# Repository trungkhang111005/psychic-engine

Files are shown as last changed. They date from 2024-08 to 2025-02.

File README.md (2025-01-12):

# Psychic-Engine: 3D-Printed RC Car Project

## Table of Contents

1. [Introduction](#1-introduction)
2. [Goals](#2-goals)
3. [Features](#3-features)
4. [Technologies Used](#4-technologies-used)
5. [Project Structure](#5-project-structure)
6. [Getting Started](#6-getting-started)
   - [Prerequisites](#61-prerequisites)
   - [Steps](#62-steps)
   - [Demo Videos](#63-demo-videos)
7. [Challenges and Solutions](#7-challenges-and-solutions)
   - [Electronics](#71-electronics)
   - [Rear Differential Drive](#72-rear-differential-drive)
   - [Steering System](#73-steering-system)
8. [Future Improvements](#8-future-improvements)
9. [License](#9-license)
10. [Acknowledgments](#10-acknowledgments)
11. [Contact](#11-contact)

<div style="text-align: center;">
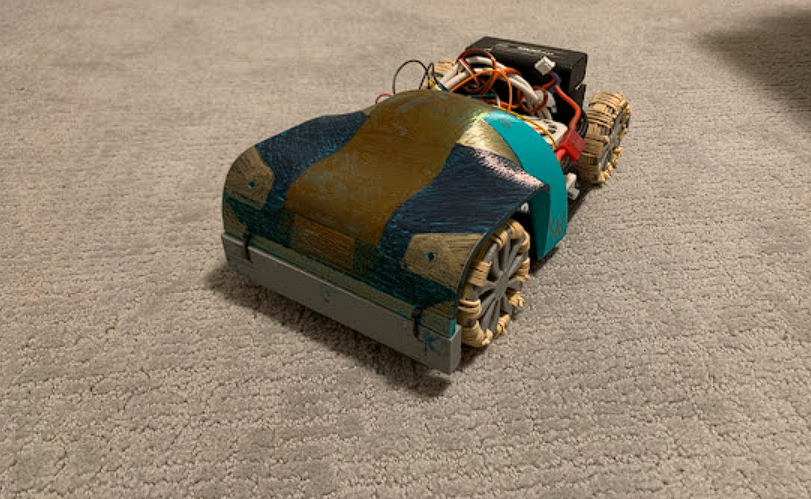
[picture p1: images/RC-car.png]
psychic-engine
    
</div>

## 1. Introduction
This project involves the design, 3D printing, and assembly of a fully functional RC car, controlled by an ESP32 microcontroller. The car features a custom-designed rear differential and a rack-and-pinion steering system based on the Ackerman principle to avoid skidding. All parts are custom-designed, with the exception of a few metal machined parts where higher durability and precision were required.

## 2. Goals

The primary goals of the Psychic-Engine 3D-Printed RC Car Project are to:

1. **Develop a Fully Functional 3D-Printed RC Car**: Design, 3D print, and assemble a reliable and robust RC car using custom-designed parts, ensuring all components fit seamlessly together and perform as intended.

2. **Implement Efficient Control Using ESP32**: Utilize the ESP32 microcontroller to achieve efficient and responsive wireless control of the car.

3. **Incorporate Advanced Steering Mechanisms**: Implement a rack-and-pinion steering system based on the Ackerman principle to improve cornering performance.

4. **Ensure Effective Power Distribution**: Create a custom rear differential that provides balanced power distribution to the wheels.

5. **Facilitate Easy Assembly**: Use snap-fit joints and compliant mechanisms to simplify assembly, reducing the need for machined fasteners.

6. **Prepare for Autonomous Features**: Lay the groundwork for autonomous navigation capabilities by planning for the integration of sensors and control systems.

These goals are designed to guide the project towards developing a versatile and innovative RC car that serves both as a functional prototype and an educational tool.

## 3. Features
1. **Custom 3D-Printed Parts**: Most components are designed in SolidWorks, 3D-printed using PLA and PETG materials.
2. **ESP32 Control**: The car is controlled using an ESP32 microcontroller, providing efficient wireless communication and processing power.
3. **Ackerman Steering System**: The rack-and-pinion steering follows the Ackerman principle to reduce tire wear and improve cornering performance.
4. **Rear Differential**: A custom-designed rear differential ensures smooth power distribution to the wheels, enhancing the car's handling.
5. **Snap Fit Joints**: Compliant mechanism is used to create snap fit joints, eliminating the need for machined fasteners.

## 4. Technologies Used
1. **CAD Software**: SolidWorks
2. **3D Printer**: Sovol SV06
3. **Materials**: PLA (Elegoo) for structural components, PETG (Overture) for functional parts
4. **Microcontroller**: ESP32
5. **Programming Language**: C++ (for Arduino/ESP32 script)

## 5. Project Structure
1. **[Structure](./Structure/)**
   - Contains the **[SolidWorks](./Structure/Solidworks/)** folder with all CAD files.
   - 3D printing instructions
   - Contains the **[Assembly_Instructions](./Structure/Assembly_Instructions/)** folder with detail images of assembly steps
2. **[Electronics](./Electronics/)**
   - Contains the **[Arduino](./Electronics/Arduino/)** folder with ESP32 scripts.
   - Setup instructions for the electronic components.

## 6. Getting Started

### 6.1 Prerequisites
1. SolidWorks (or any CAD software) installed for viewing and modifying CAD files.
2. Slicing software suitable for your printer.
3. Arduino IDE configured to work with ESP32 for uploading the script.
4. A Sovol SV06 3D printer (or any FDM printer) with a print plate size of at least 235x235 mm.

### 6.2 Steps

1. **3D Printing the Parts**:
   - Navigate to the **[Structure](./Structure/)** folder.
   - Follow the instructions provided in the 3D printing instructions file to prepare and print all the necessary components.

2. **Assembling the Car**:
   - Go to the **[Assembly_Instructions](./Structure/Assembly_Instructions/)** subfolder.
   - Follow the detailed assembly instructions provided to assemble the 3D-printed parts into the final RC car structure.

3. **Setting Up Electronics**:
   - Navigate to the **[Electronics](./Electronics/)** folder.
   - Follow the instructions provided to connect the Xbox controller to the ESP32 microcontroller.
   - Refer to the motor/servo wiring instructions to correctly wire the motor and servo to the ESP32.

### 6.3 Demo Videos
RC car in details

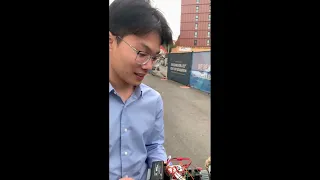
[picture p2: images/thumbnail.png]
Watch me talking about the RC car and a demo of it in action (https://youtu.be/J6uigz7IrvU)


Drifting

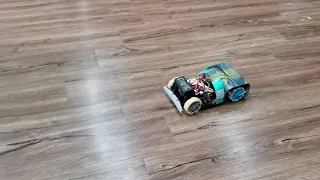
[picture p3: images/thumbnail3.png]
Watch the car drifting (https://youtu.be/YaZgg8Mr1b0?feature=shared)


Testing

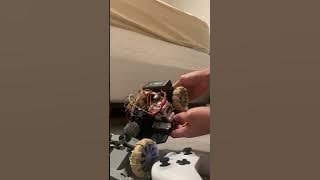
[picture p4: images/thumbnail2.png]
Watch the RC car in testing (https://youtu.be/PcJJqVZroOI?si=CFPb1v_Qr5A0FJ0J)


## 7. Challenges and Solutions

The development of the RC car was segmented into three primary components: electronics, rear differential drive, and steering. Each component presented distinct challenges that required tailored engineering solutions.

### 7.1 Electronics
1. **Challenge**: Difficulty in establishing a Bluetooth Low Energy (BLE) connection between the Xbox controller and the ESP32 microcontroller.
   - **Solution**: After conducting extensive research, the Bluepad library was identified and utilized. This library provided the necessary support for BLE connections, enabling seamless communication between the Xbox controller and the ESP32.

2. **Challenge**: Arming the motor via the Xbox controller and ESP32 was problematic due to the absence of a conventional radio controller.
   - **Solution**: A script found on the [Arduino forum](https://forum.arduino.cc/t/lessons-on-arming-esc-with-arduino/427152) facilitated the identification of the correct arming PWM signals for the ESC. Implementing this script allowed for successful motor arming and control.

### 7.2 Rear Differential Drive
1. **Challenge**: The gearbox experienced displacement from the pinion gear during operation, compromising gear engagement and overall performance.
   - **Solution**: A structural enhancement was made by designing a three-arm system that extends from the chassis to apply pressure on the gearbox, maintaining optimal engagement with the pinion gear. Castor balls were integrated at the arm ends to minimize friction, facilitating smooth high-speed rotation of the ring gear.

2. **Challenge**: High stress concentrations led to frequent axle breakage.
   - **Solution**: Structural integrity was improved by introducing fillets at critical stress points behind the wheel and axle gear, promoting even stress distribution. Additionally, the infill percentage was increased, and a triangular infill pattern was adopted to enhance the axle's durability.

### 7.3 Steering System
1. **Challenge**: Determining the precise length of the steering tie rod was complex, resulting in difficulties in maintaining the steering wheels' alignment.
   - **Solution**: SolidWorks was employed to assemble the steering rack and knuckles in a virtual environment. This facilitated accurate determination of the tie rod length, ensuring consistent and correct alignment of the steering wheels.

2. **Challenge**: The tie rod had a propensity to become misaligned and rotate inwards, risking damage to the servo by causing it to lock or break during excessive rack movement.
   - **Solution**: To mitigate this issue, two structural poles were added to the chassis, acting as physical stops. These stops prevent excessive inward rotation of the tie rods, thereby safeguarding the servo from potential damage.

### Summary

By methodically addressing each engineering challenge, the RC car project achieved a robust and reliable design. The implemented solutions not only resolved the specific issues but also enhanced the car's overall performance and structural integrity, ensuring its capability to withstand various operating conditions.

## 8. Future Improvements

Looking forward, several enhancements are planned to elevate the functionality and user experience of the RC car:

1. **Integrating an IMU and OpenPilot**: To enable autonomous navigation capabilities, the integration of an Inertial Measurement Unit (IMU) along with the [OpenPilot](https://github.com/commaai/openpilot.git) system is proposed. This will allow the car to navigate and maneuver independently based on pre-defined parameters and real-time sensor data.

2. **Adding a First-Person Camera with Microphone**: To enhance the user experience and expand the car's applications, a first-person view (FPV) camera will be installed alongside a microphone to capture ambient sounds. This setup will enable the car to be used for inspections and monitoring in various settings such as factories, construction sites, or natural environments, providing both visual and auditory feedback.

3. **Transitioning to Radio Signal Control**: To extend the operational range and reliability of the control system, the project plans to transition from Bluetooth to radio signal-based control. This shift will allow for longer-range operation and a more stable connection, improving the car’s performance in various environments.

4. **Solar-Powered Charging System**: Integrating solar panels into the car's design is planned to provide an additional power source. This could supplement the battery or allow for continuous operation in sunny conditions, increasing the car's autonomy and reducing the need for frequent battery charging.

## 9. License
- The ESP32 script is licensed under the MIT License.
- The SolidWorks design files are licensed under the Creative Commons Attribution 4.0 International License.

## 10. Acknowledgments
- Special thanks to Brendon Kennard for providing the BLDC motor for this project.
- Thanks to [Bluepad32](https://github.com/ricardoquesada/bluepad32.git) for the initial ESP32 code framework.
- Thanks to [The Engineering Mindset](https://youtu.be/vpbhvxAM0io?si=aknrSyXhpb9AykjJ) for inspiring the modelling of the differntial gearbox model.

## 11. Contact
If you have any questions or want to collaborate, feel free to reach out to me at trungkhang1110@gmail.com.

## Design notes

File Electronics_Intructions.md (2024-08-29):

# Electronics Setup

## Components Needed
- **Controller**: bluetooth supported controller (Xbox, etc.)
- **Microcontroller**: ESP32
- **Motor**: Surpass Hobby Platinum Waterproof Series, 28 mm diameter, 47 mm length
- **ESC**: Surpass Hobby Platinum Waterproof 45 A
- **Buck Converter**: LM2596
- **Servo**: SG 5010
- **MOSFET**: IRL 530N
- **Resistor**: 1 x 100 ohm
- **Jumper Wires**
- **Breadboard**: 1 x mini 20-holes long breadboard
- **Battery**: 2S/3S lithium polymer battery 1500mAh
- **Double-Sided Tape**
- **Rubber Bands**

## Setting Up ESP32 and Bluepad on Arduino IDE
1. **Install the ESP32 Board in Arduino IDE**:
   - Open Arduino IDE.
   - Go to `File > Preferences`.
   - Add these URLs in the "Additional Boards Manager URLs" field:
     ```
     https://espressif.github.io/arduino-esp32/package_esp32_dev_index.json
     https://raw.githubusercontent.com/espressif/arduino-esp32/gh-pages/package_esp32_index.json
     https://raw.githubusercontent.com/ricardoquesada/esp32-arduino-lib-builder/master/bluepad32_files/package_esp32_bluepad32_index.json
     ```
   - Go to `Tools > Board > Boards Manager`, search for "ESP32", and install.
   - Select ESP32 Dev Module board or esp32 board of your choice.

2. **Install Bluepad32 Library**:
   - Go to `Tools > Manage Libraries`, search for "Bluepad32", and install it.

3. **Upload the Arduino Script**:
   - Connect the ESP32 via USB.
   - Open the script from the [](Arduino) folder.
   - Select the correct board and port, then upload the script.
   - turn on your controller and pair the controller with the esp32
## Layout and Wiring
1. **Component Placement**:
   - Place the MOSFET and buck converter on the breadboard.
   - Use double-sided tape and rubber bands for securing components.

2. **Wiring**:
   - **Buck Converter Setup**:
     - Connect the positive of the BEC to the buck converter input.
     - Connect the ground of the BEC to the buck converter ground.
     - Adjust the output to 3.3V.
     - Connect the buck converter output to the 3V3 pin on the ESP32.

   - **Servo Connection**:
     - Place MOSFET on the breadboard without shorting pins.
     - Connect a 100 ohm resistor between the MOSFET gate (1st pin) and ESP32 pin 27.
     - Connect the servo signal wire to ESP32 pin 13.
     - Connect servo power to the same row as BEC positive.

## Testing
1. Power up the setup and verify signals to motor and servo.
2. Use the Arduino IDE serial monitor for debugging.

## Usage
- Power on the car by connecting the battery to the ESP32.
- Use the controller to navigate the car.

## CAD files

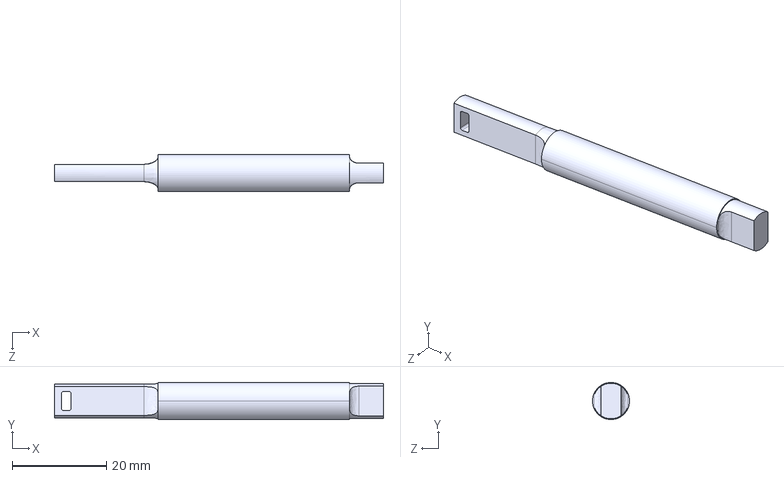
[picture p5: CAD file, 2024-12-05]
Structure/.step/diff axel right side.STEP
70.0 x 7.90 x 7.90 mm

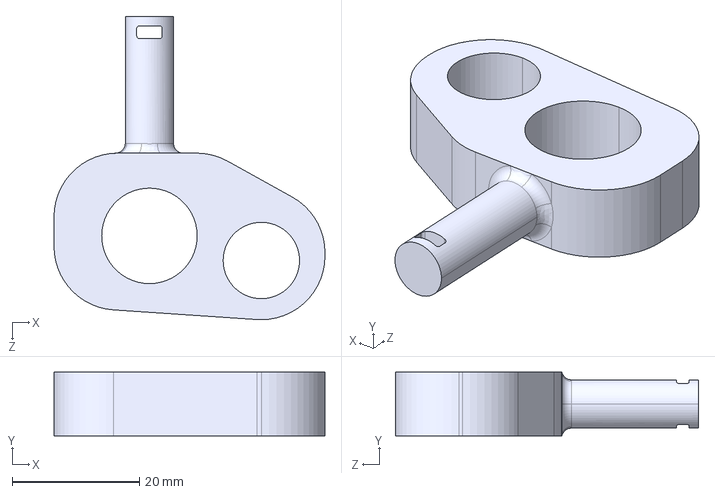
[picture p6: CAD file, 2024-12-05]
Structure/.step/steering knuckle (print 2).STEP
42.6 x 10.0 x 47.7 mm

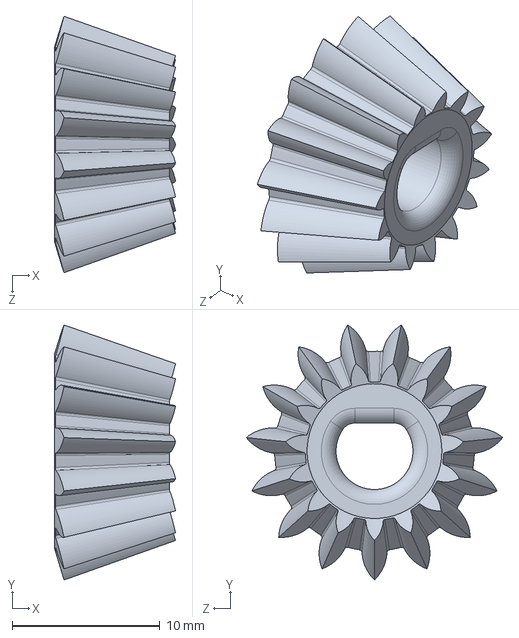
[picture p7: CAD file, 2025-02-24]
Structure/Solidworks/3665 pinion.SLDPRT
8.19 x 17.3 x 17.4 mm

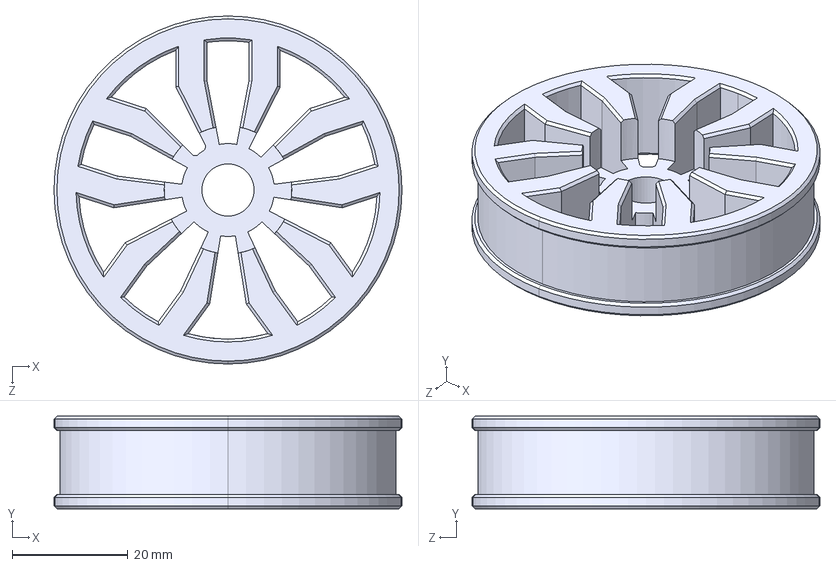
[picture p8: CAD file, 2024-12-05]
Structure/.step/front wheel (print 2).STEP
60.0 x 16.0 x 60.0 mm

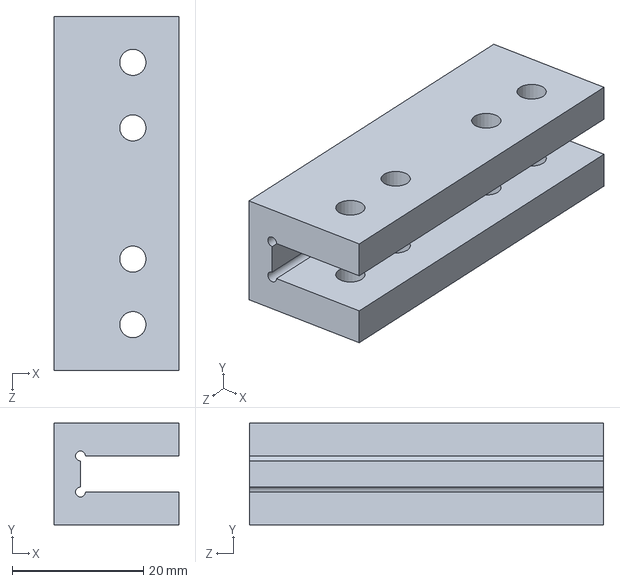
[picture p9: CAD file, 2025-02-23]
Structure/Solidworks/chassis_connector.SLDPRT
19.0 x 15.5 x 54.0 mm

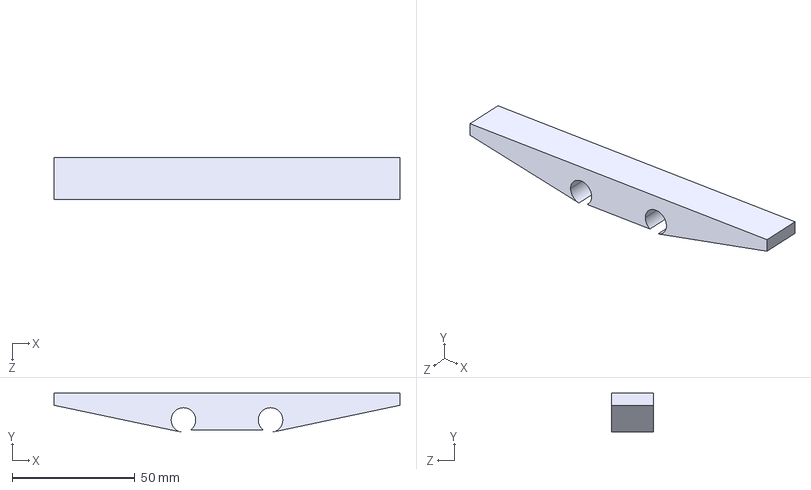
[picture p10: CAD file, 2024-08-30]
Structure/.step/rear bumper.STEP
141.0 x 15.9 x 17.0 mm

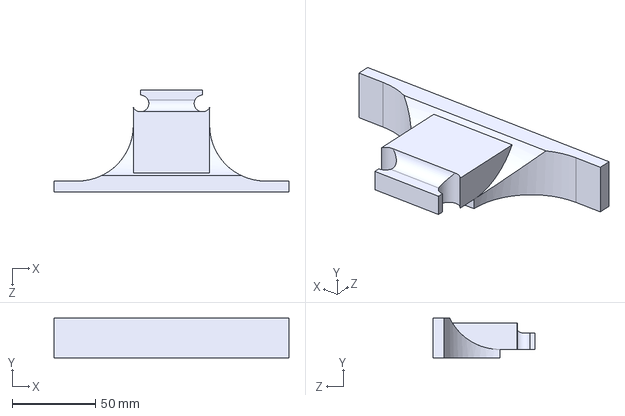
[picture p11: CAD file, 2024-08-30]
Structure/.step/front bumper.STEP
141.0 x 23.7 x 61.1 mm

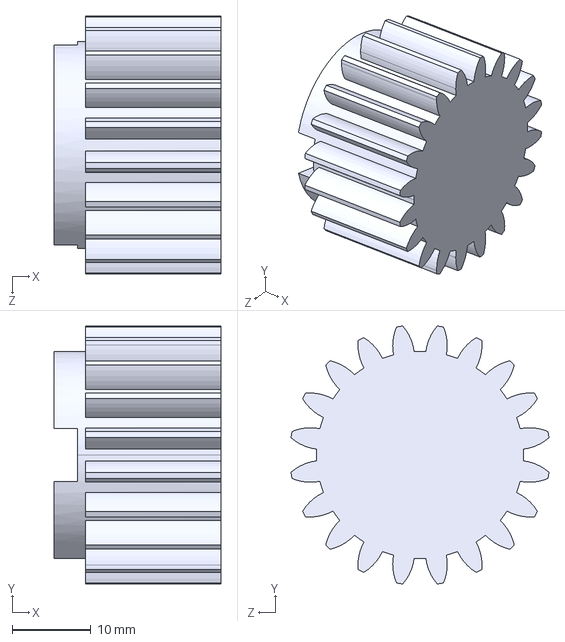
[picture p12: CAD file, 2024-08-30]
Structure/.step/steering pinion.STEP
21.2 x 32.7 x 32.7 mm

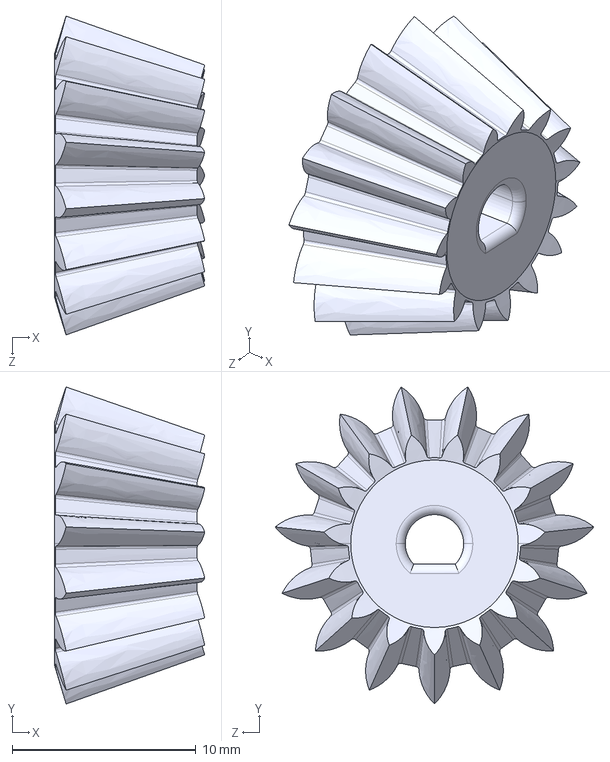
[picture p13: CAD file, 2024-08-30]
Structure/.step/diff pinion gear.STEP
8.19 x 17.3 x 17.4 mm

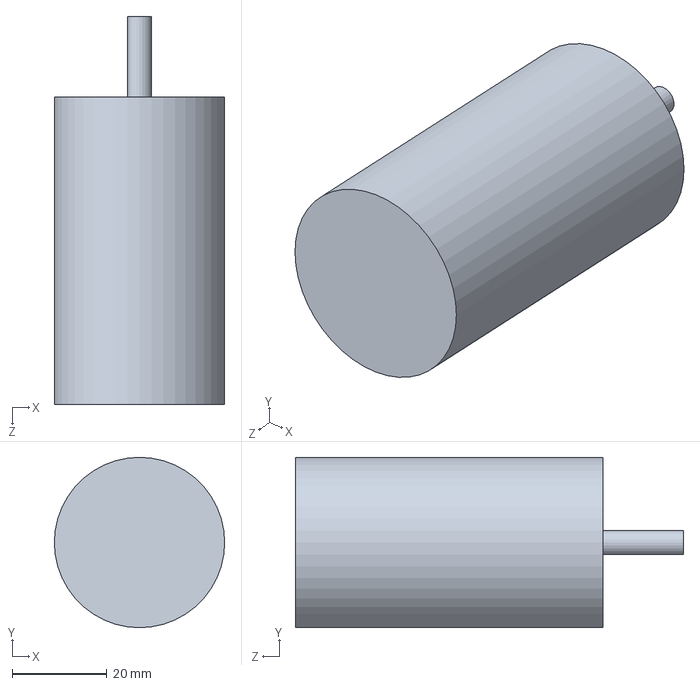
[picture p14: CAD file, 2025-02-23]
Structure/Solidworks/model 3665 motor.SLDPRT
36.0 x 36.0 x 82.0 mm

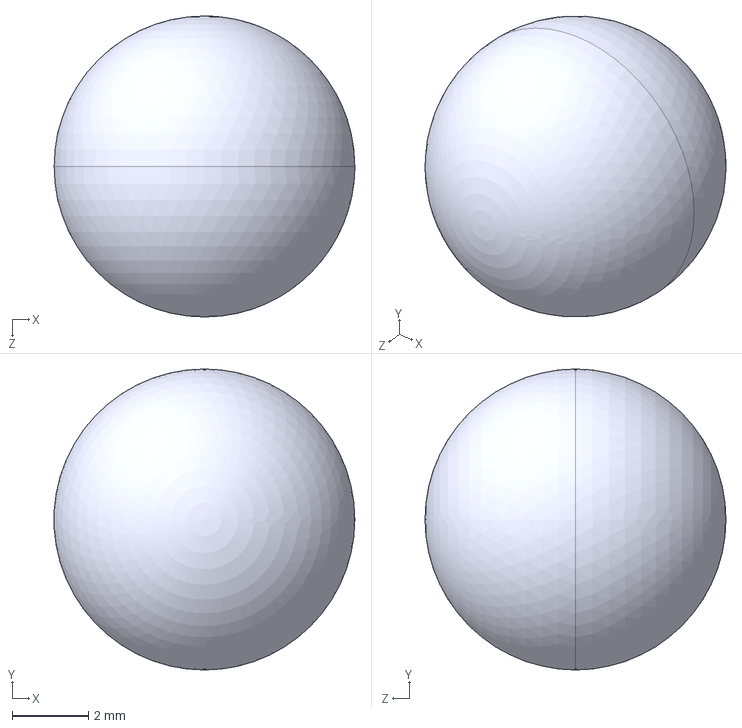
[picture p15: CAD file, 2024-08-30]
Structure/.step/diff ball castor (print 3).STEP
7.89 x 7.90 x 7.90 mm

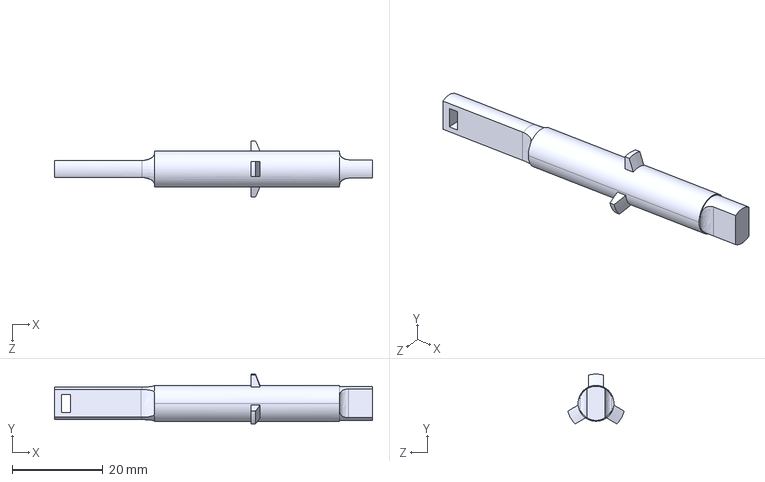
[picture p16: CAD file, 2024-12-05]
Structure/Solidworks/diff axel left side.STEP
70.0 x 11.0 x 12.4 mm

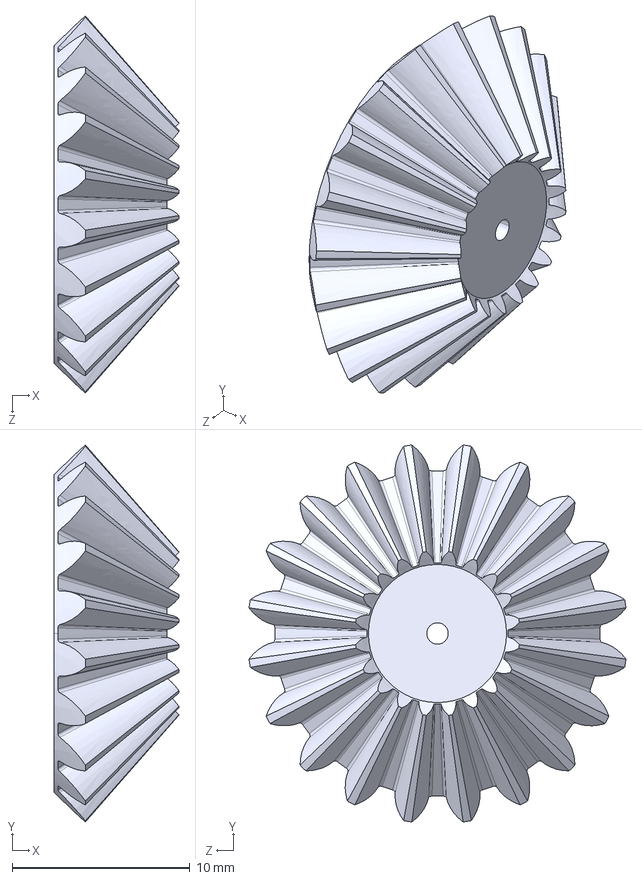
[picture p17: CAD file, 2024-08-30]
Structure/.step/diff case gear (print 2).STEP
7.02 x 21.2 x 21.2 mm

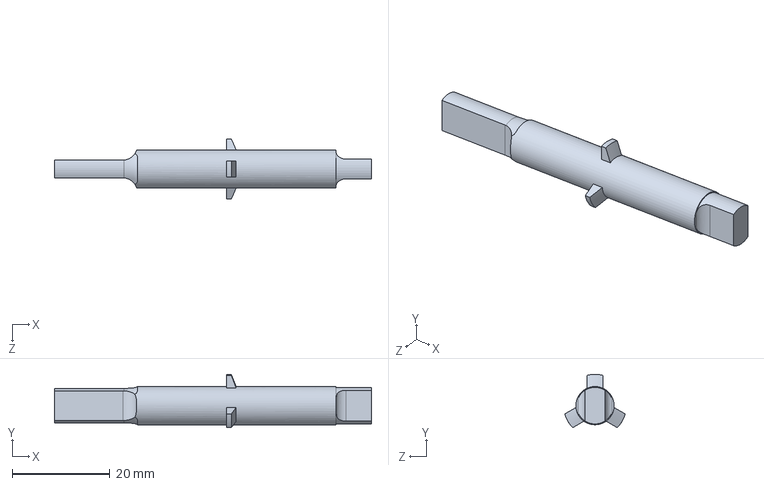
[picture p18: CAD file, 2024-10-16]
Structure/Solidworks/diff axel left side smaller for petg.SLDPRT
65.0 x 10.9 x 12.4 mm

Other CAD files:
Structure/Solidworks/new_assembly.SLDASM
Structure/Solidworks/RC car.SLDASM
Structure/.step/rear wheel (print 2).STEP
Structure/.step/diff ring gear.STEP
Structure/.step/chassis.STEP
Structure/.step/diff axel gear (print 2).STEP
Structure/.step/diff axel left side.STEP
Structure/.step/steering knuckle cover (print 2).STEP
Structure/.step/steering rack.STEP
Structure/.step/steering tie rod (print 2).STEP
Structure/.stl/3665 pinion.STL
Structure/.stl/chassis - Copy (2).STL
Structure/.stl/chassis - Copy.STL
Structure/.stl/chassis.STL
Structure/.stl/chassis_connector.STL
Structure/.stl/diff axel gear (print 2).STL
Structure/.stl/diff axel left side smaller for petg.STL
Structure/.stl/diff axel left side.SLDPRT
Structure/.stl/diff axel left side.STL
Structure/.stl/diff axel right side.STL
Structure/.stl/diff ball castor (print 3).STL
Structure/.stl/diff case gear (print 2).STL
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

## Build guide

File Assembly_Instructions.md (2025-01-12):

# Structure Assembly Guide

## Chassis and Mechanical Assembly

### Step 1: Insert the Castor Balls and Bearings
Insert the 3 castor balls into the rear wheel castor ball slots, then insert the 2 bearings into their respective slots.

<div style="text-align: center;">
    Castor Ball Insertion
</div>

### Step 2: Secure the Motor
Lock the motor into its place with M3 screws. Ensure the screws are firmly tightened, as vibrations from the motor can loosen the screws over time.

<div style="text-align: center;">
    Motor Secured with Screws
</div>

### Step 3: Install the Pinion Gear
Use a bar or F-clamp to press the pinion gear onto the motor shaft. The interference fit requires significant force to install. Make sure the top of the pinion gear aligns with the middle of the side castor ball.

<div style="text-align: center;">
    Pinion Gear Installation
    Pinion Gear Alignment
</div>

### Step 4: Insert the Right Rear Wheel Axle
Insert the right rear wheel axle into its designated slot.

<div style="text-align: center;">
    Right Rear Wheel Axle Insertion
</div>

### Step 5: Assemble the Differential Gearbox
1. Assemble the differential gearbox.
2. Fasten the 2 case gears into the gearbox using the fishing line that runs through both of them. Tie a double knot on top of the gearbox.

   <div style="text-align: center;">
       Differential Gearbox Assembly
   </div>

3. Insert the 2 axle gears simultaneously, placing each on opposite sides of the gearbox first, then pushing them into place. Look down from the top of the gearbox to see if the axle gears are properly aligned (you should be able to see through the axle slots).

   <div style="text-align: center;">
       Axle Gear Insertion
       Axle Gear Alignment Check
   </div>

### Step 6: Position the Gearbox
Slide the gearbox at an angle between the right axle and the pinion gear to fix it in place.

<div style="text-align: center;">
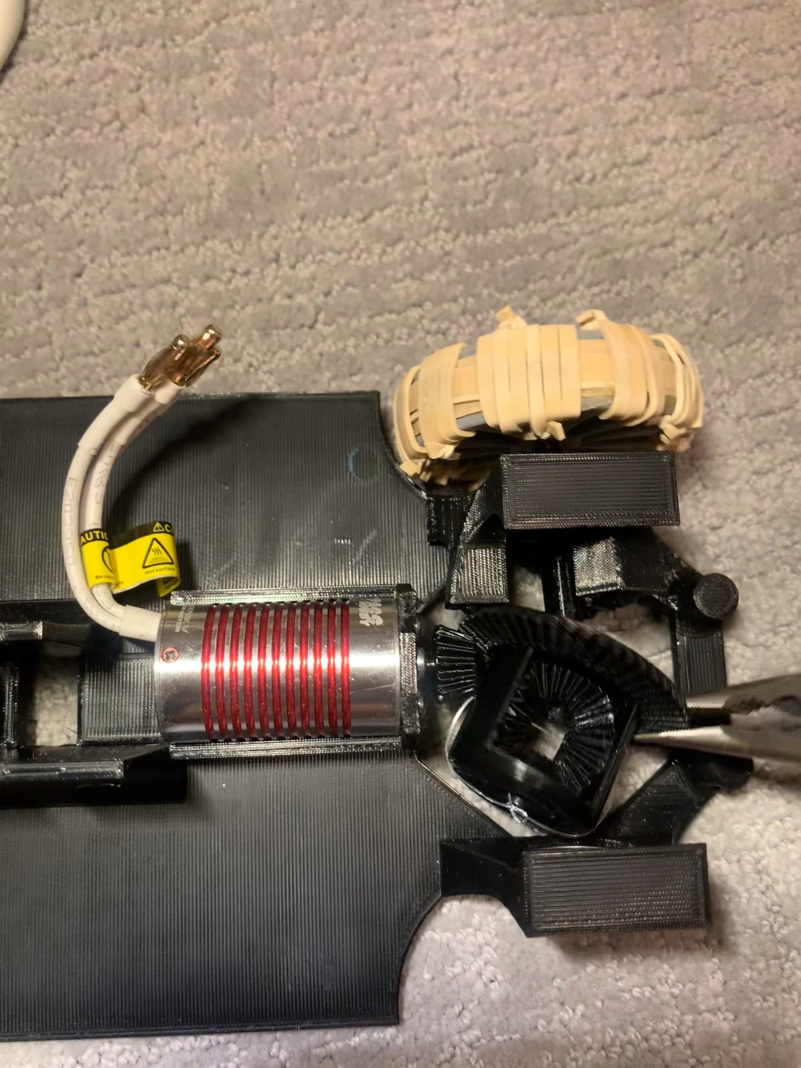
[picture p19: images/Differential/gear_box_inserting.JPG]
Gearbox Positioning
    
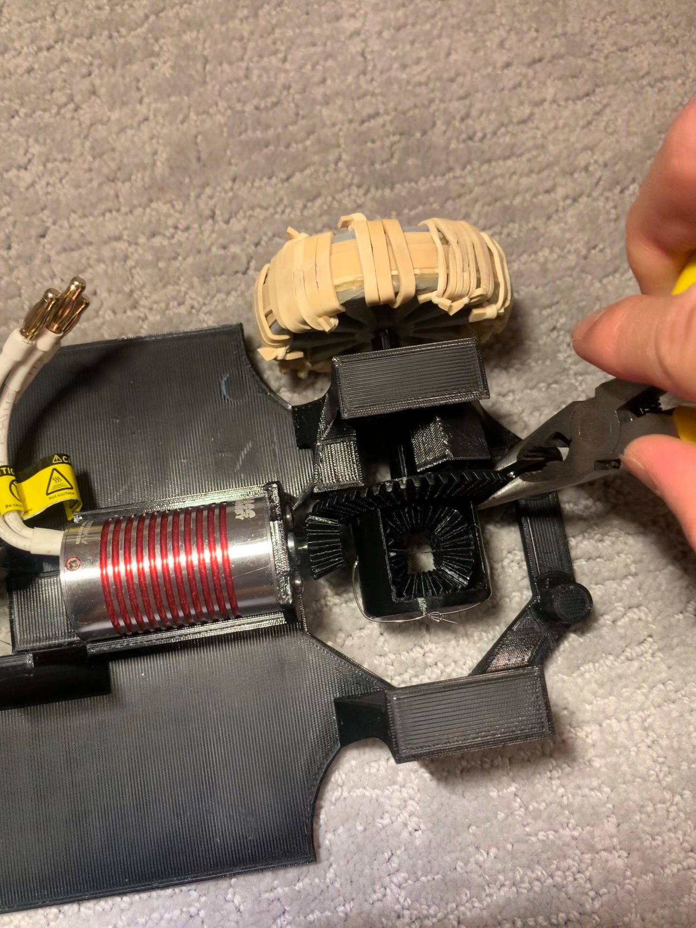
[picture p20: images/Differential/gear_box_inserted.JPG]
Gearbox Positioned
    
</div>

### Step 7: Insert the Left Axle
Insert the left axle and fix the gearbox in its axis.

<div style="text-align: center;">
    Left Axle Insertion
</div>

### Step 8: Attach the Wheels
Insert the wheels onto the axles.

### Step 9: Secure Wheels with Glue
Use a glue gun to secure the wheels to the axles. The interference fit provides most of the hold, but the glue is an extra measure.

### Steering Assembly

### Step 10: Install the Steering Rack
Insert the steering rack into its designated slot.

### Step 11: Attach the Steering Pinion
Use a glue gun to attach the steering pinion to the servo horn. Then attach the pinion gear to the servo and insert the servo into its place.

<div style="text-align: center;">
    Steering Pinion Attachment
    Steering Servo Inserting
</div>

### Step 12: Assemble the Front Wheels and Knuckles
1. Use super glue or a glue gun to attach the bearings to the front wheels.
2. Attach the steering knuckles to the bearings.

### Step 13: Install Steering Knuckles
Insert the knuckles into their slots and cover them with the steering knuckle covers. Use at least 2 rubber bands to keep the covers in place. The rubber bands will also act as a suspension. Tie the rubber bands on the bottom side.

<div style="text-align: center;">
    Steering Knuckle Installation
</div>

### Step 14: Connect the Steering Tie Rod
Use the steering tie rod to connect the steering rack to the steering knuckles.

### Step 15: Place Electronics
Double-sided tape the ESC, breadboard, and buck converter. Lay the ESC on the left side of the chassis, the breadboard, and the buck converter on the right side.

### Step 16: Follow Electronics Setup
Follow the steps detailed in the [Electronics Setup Guide](Electronics_Instructions.md).

### Step 17: Attach Bumpers
Insert the front and rear bumpers into their designated slots. No glue is needed as they fit securely with interference fit.

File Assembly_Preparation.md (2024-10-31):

# Structure Assembly Guide

## Components Needed
### 3D-Printed Parts
- **PLA**: Chassis, bumpers, wheels, steering pinion (gyroid infill, 10-25% infill).
- **PETG**: All other components (50-75% infill, gyroid or triangle infill).

### Non-3D Printed Components
- **Bearings**: 4 x 608 2RS bearings
- **Screws**: 4 x M3x10mm screws
- **Rubber Bands**
- **Clamp**: Irwin clamp / bar clamp
- **Glue Gun**
- **Fishing line**

## Motor Compatibility
- Use a motor with a diameter between 25 mm and 29 mm, and length of 47 mm.
- Adjust chassis file for motor diameter if outside standard range (add 0.5 mm for printing tolerance).

## 3D Printing Instructions
1. **Material Selection**:
   - **PLA**: For chassis, bumpers, wheels, steering pinion.
   - **PETG**: For all other components.

2. **Infill Settings**:
   - **PLA Parts**: 10-25% infill, gyroid for steering pinion.
   - **PETG Parts**: 50-75% infill, gyroid or triangle for strength.

3. **Printing Process**:
   - Download CAD files from the [Solidworks](Solidworks), [.step](.step) or [.stl](.stl) folder.
   - Slice parts based on material and infill settings.
   - Print using a 3D printer with a plate size of at least 235x235 mm.

## Assembly Steps
1. **Chassis and Steering Assembly**:
   - Follow instructions in [](Assembly_Instructions/README.md) for detailed instructions.
   - Attach the steering and differential parts.

2. **Motor and Electronics Mounting**:
   - Secure motor to the chassis.
   - Integrate electronics following the [](../Electronics/README.md`).

## Testing and Adjustments
- Ensure all parts are fitted securely.
- Test mechanical components before full assembly.

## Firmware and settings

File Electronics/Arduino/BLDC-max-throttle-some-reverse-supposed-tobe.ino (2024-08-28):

#include <Arduino.h>
#include <Bluepad32.h>
#include <ESP32Servo.h>

// Define the GPIO pin connected to the MOSFET
#define MOSFET_PIN 27
Servo myMotor;
Servo myServo;

ControllerPtr myControllers[BP32_MAX_GAMEPADS];
unsigned long controllerConnectedTime = 0;
bool controllerJustConnected = false;

void setup() {
  pinMode(MOSFET_PIN, OUTPUT);
  digitalWrite(MOSFET_PIN, LOW);  // Start with the MOSFET off

  myServo.attach(13);
  myMotor.attach(14);  // Attach the servo to GPIO 12
  BP32.setup(onConnectedController, onDisconnectedController);
  Serial.begin(115200);
  BP32.forgetBluetoothKeys();  // Optional, for clean pairing
}

void loop() {
  if (BP32.update()) {  // Check for controller updates
    for (auto &ctl : myControllers) {
      if (ctl && ctl->isConnected() && ctl->hasData()) {
        if (ctl->isGamepad()) {
          processGamepad(ctl);
        }
      }
    }
  }

  // Check if the controller was just connected and 3 seconds have passed
  if (controllerJustConnected && (millis() - controllerConnectedTime >= 3000)) {
    digitalWrite(MOSFET_PIN, HIGH);  // Turn on the MOSFET
    controllerJustConnected = false; // Reset the flag
  }
}

void onConnectedController(ControllerPtr ctl) {
  for (int i = 0; i < BP32_MAX_GAMEPADS; i++) {
    if (myControllers[i] == nullptr) {
      myControllers[i] = ctl;
      Serial.printf("Gamepad connected on index=%d\n", i);
      controllerConnectedTime = millis(); // Set the connection time
      controllerJustConnected = true; // Set the flag
      break;
    }
  }
}

void onDisconnectedController(ControllerPtr ctl) {
  for (int i = 0; i < BP32_MAX_GAMEPADS; i++) {
    if (myControllers[i] == ctl) {
      myControllers[i] = nullptr;
      Serial.printf("Gamepad disconnected from index=%d\n", i);
      if (!isAnyControllerConnected()) {
        digitalWrite(MOSFET_PIN, LOW);  // Turn off the MOSFET if no controllers are connected
      }
      break;
    }
  }
}

bool isAnyControllerConnected() {
  for (auto &ctl : myControllers) {
    if (ctl != nullptr) {
      return true;
    }
  }
  return false;
}

void processGamepad(ControllerPtr ctl) {
  int throttleValue = ctl->throttle();
  int brakeValue = ctl->brake();
  int joystickValue = ctl->axisX();
  int forwardSpeed = 0, reverseSpeed = 0;
  int servoPosition = map(joystickValue, -511, 512, 50, 131);
if (ctl->a())
{
   forwardSpeed = map(throttleValue, 0, 1023, 90, 70);
}
else
{
  forwardSpeed = map(throttleValue, 0, 1023, 90, 77);
}
  reverseSpeed = map(brakeValue, 0, 1023, 90, 103);
  if (ctl->axisX() > -1 && ctl->axisX() < 58) {
    myServo.write(90);
  } else {
    myServo.write(servoPosition);
  }

  if (ctl->brake() > 100) {
    myMotor.write(reverseSpeed);}
  else if (ctl->throttle() > 100) {
    myMotor.write(forwardSpeed);
  }

  if (ctl->throttle() < 100 && ctl->brake() < 100) {
    myMotor.write(90);
  }

  Serial.printf("joystick %d\n", ctl->axisX());
}

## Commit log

2024-08-28 Add Ardunino code, Solidworks files, and Readme.me for assembly instructions
    [MODEL 2s battery.SLDPRT, MODEL 608 2RS bearing (need 4).SLDPRT, MODEL SG 5010 servo.SLDPRT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]
2024-08-30 Adding step and stl 3d model files
    [chassis.STEP, chassis.STL, diff axel gear (print 2).STEP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]
2024-10-16 UPDATE LEFT AXEL
    [diff axel left side smaller for petg.SLDPRT]
2024-12-05 modifying steering kuckle, front wheel, back axels to work with cotter pins
    [diff axel left side.SLDPRT, diff axel left side.STL, diff axel right side.SLDPRT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]
2024-12-05 modified component to work with cotter pins"
    [diff axel left side.STEP, diff axel right side.STEP, front wheel (print 2).STEP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]
2025-02-23 add cut in half chassises and chassis connector, both sldpart and stl
    [RC car.SLDASM, chassis - Copy (2).SLDPRT, chassis - Copy (2).STL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]
2025-02-24 add 3665 pinion stl and sldpart
    [3665 pinion.SLDPRT, 3665 pinion.STL]
2025-03-02 add steer pinion bore
    [steering pinion.SLDPRT, steering pinion.STL]
2025-03-04 add pin holes in axels
    [diff axel left side.SLDPRT, diff axel left side.STL, diff axel right side.SLDPRT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]
2025-03-05 change rear axle and wheel design, goal is better strength. last design has high broken chance
    [diff axel left side.SLDPRT, diff axel right side.SLDPRT, diff axel right side.STL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]
2025-03-05 change axel left side locking mechanism similar to right side
    [diff axel left side.SLDPRT, diff axel left side.STL, diff axel right side.SLDPRT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]
